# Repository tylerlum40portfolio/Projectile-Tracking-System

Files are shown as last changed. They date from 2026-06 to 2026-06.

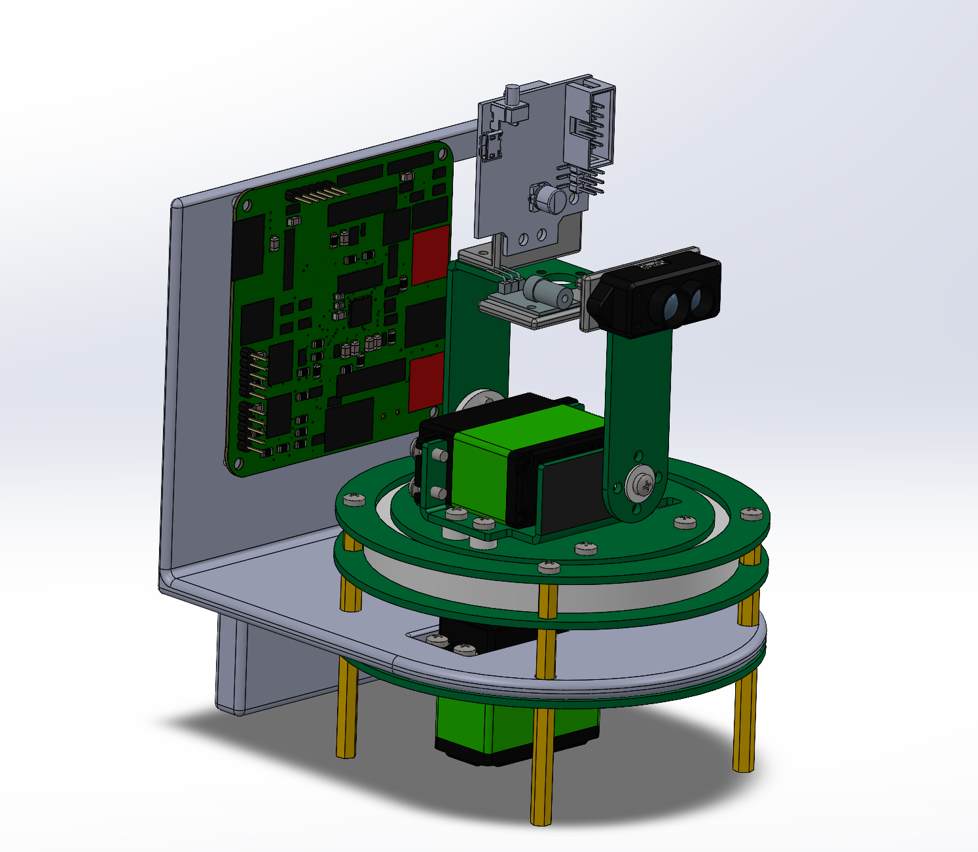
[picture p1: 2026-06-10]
images/Full 3D Assembly.png

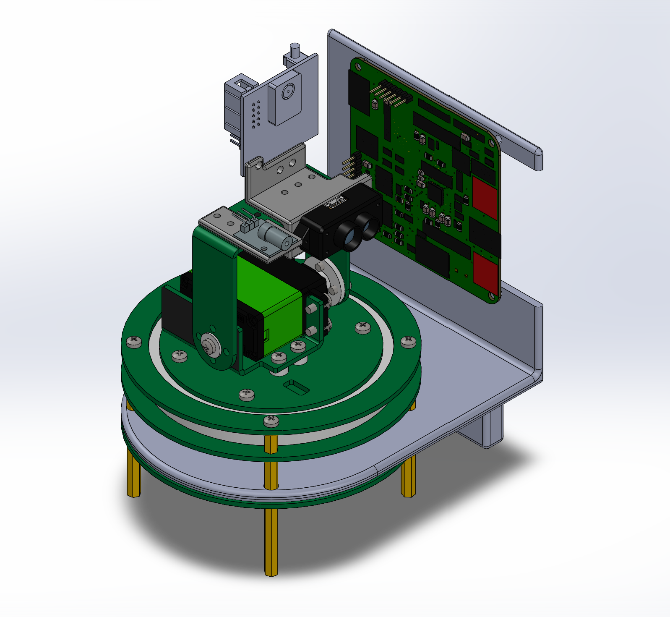
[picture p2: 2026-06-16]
images/fig-16-full-assembly.png

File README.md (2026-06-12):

# Pan-Tilt Laser Tracker

## Overview

The Pan-Tilt Laser Tracker is an STM32F411-based embedded mechatronic system designed to automatically detect, track, and indicate the location of a target in real time. The system combines computer vision, distance sensing, embedded control, and custom electronics into a single integrated platform.

A Pixy2 vision camera is used to detect a colored target and determine its position within the camera image. A TF-Luna LiDAR sensor provides distance measurements to validate target range. A custom controller processes this information and commands pan and tilt motors to continuously align the system with the target. A laser module is used to indicate the current tracked location.

The project was developed as part of ME 405 Mechatronics at California Polytechnic State University, San Luis Obispo and demonstrates many of the embedded systems, control, sensing, and software engineering concepts covered throughout the course.

---

## Team Members

- Tyler Lum
- Colby Cordoba
- Sam Nunes

Mechanical Engineering – Mechatronics

California Polytechnic State University, San Luis Obispo

---

## Project Features

### Sensing

- Real-time target detection using a Pixy2 vision sensor
- Distance measurement using TF-Luna LiDAR
- Target validation based on camera and distance data
- Sensor data filtering and validation

### Actuation

- Pan-axis motor control
- Tilt-axis motor control
- Laser target indication
- Closed-loop target tracking

### Embedded Systems

- STM32F411 microcontroller
- SPI communication with Pixy2 camera
- UART communication with TF-Luna LiDAR
- PWM motor control using STM32 timers
- GPIO control for laser operation
- Modular embedded C firmware architecture

---

## Major Hardware

### Electrical Components

- STM32F411 Microcontroller
- Pixy2 Camera
- TF-Luna LiDAR Sensor
- Custom PCB
- Laser Module
- Voltage Regulation Circuitry
- SWD Programming Interface

### Mechanical Components

- Pan/Tilt Tracking Assembly
- Camera Mount
- LiDAR Mount
- Laser Mount
- PCB Mounting Bracket
- Structural Support Components

---

## Software Architecture

The firmware is organized into modular drivers and application layers.

### Main Application

The main application initializes all peripherals, configures the hardware interfaces, and executes the primary tracking loop. It coordinates communication between the sensors, controller, and actuators.

### Controller Module

The controller module serves as the intelligence layer of the system. It processes Pixy2 target information and LiDAR distance measurements, computes tracking error, and generates motor commands to maintain target alignment.

### Motor Driver

The motor driver provides an abstraction layer for pan and tilt actuation. The driver handles PWM generation, motor direction control, speed limiting, and safe motor shutdown.

### LiDAR Driver

The LiDAR driver manages UART communication with the TF-Luna sensor. The driver validates measurement frames, checks data integrity, and provides distance measurements to the controller.

### Pixy2 Driver

The Pixy2 driver handles SPI communication with the camera and processes detected object information. The driver extracts target location information used by the tracking controller.

### Laser Driver

The laser driver manages laser activation and indication logic based on controller state and target lock conditions.

---

## Tracking Algorithm

The tracking system operates using the following sequence:

1. Acquire target location from the Pixy2 camera.
2. Acquire distance measurement from the TF-Luna LiDAR.
3. Validate target detection and range.
4. Compute horizontal and vertical tracking error.
5. Generate pan and tilt motor commands.
6. Update motor outputs.
7. Activate laser when tracking criteria are satisfied.
8. Repeat continuously during operation.

---

## Mathematical Modeling and Sensor Processing

Several calculations are performed within the firmware to convert sensor measurements into motor commands.

### Pixel Error Calculation

The controller calculates the difference between the target position and the image center.

```text
Error = Target Position − Image Center
```

The resulting horizontal and vertical error values are used to determine pan and tilt corrections.

### Motor Command Generation

Tracking error is converted into motor commands using proportional control and output limiting to ensure stable operation.

### Distance Validation

LiDAR measurements are checked against valid operating ranges before tracking commands are issued. This prevents false target responses caused by invalid sensor readings.

---

## Repository Structure

```text
Projectile-Tracking-System/
│
├── Core/
│   ├── Inc/
│   └── Src/
│
├── Drivers/
│
├── docs/
│   └── Doxygen Documentation
│
├── images/
│   └── CAD Models, PCB Images, and Project Photos
│
├── index.html
├── README.md
├── Doxyfile
├── .gitignore
```

---

## Documentation

### Project Portfolio

https://tylerlum40portfolio.github.io/Projectile-Tracking-System/

### Doxygen Documentation

https://tylerlum40portfolio.github.io/Projectile-Tracking-System/docs/index.html

The Doxygen documentation contains:

- File documentation
- Function documentation
- Driver descriptions
- Data structures
- Source code references
- Module relationships

---

## Repository Requirements

This repository contains:

- Complete STM32 source code
- Doxygen-generated documentation
- Doxyfile configuration
- Project portfolio website
- CAD renders
- PCB images
- Wiring diagrams
- Mechanical design documentation
- Software architecture documentation
- Project media and demonstration materials

---

## Future Improvements

Potential future improvements include:

- Position feedback using encoders
- Improved target prediction algorithms
- Additional sensor fusion techniques
- Enhanced filtering for sensor measurements
- Improved tracking accuracy and stability

---

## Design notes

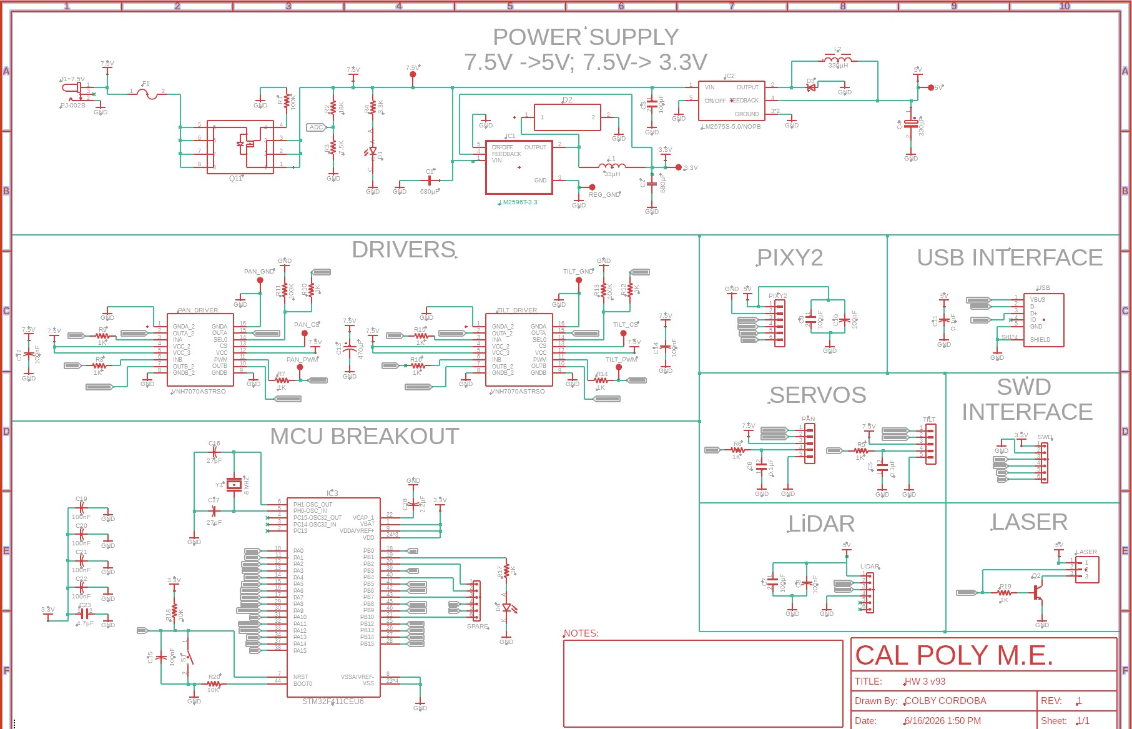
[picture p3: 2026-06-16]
images/fig-06-electrical-schematic.jpg

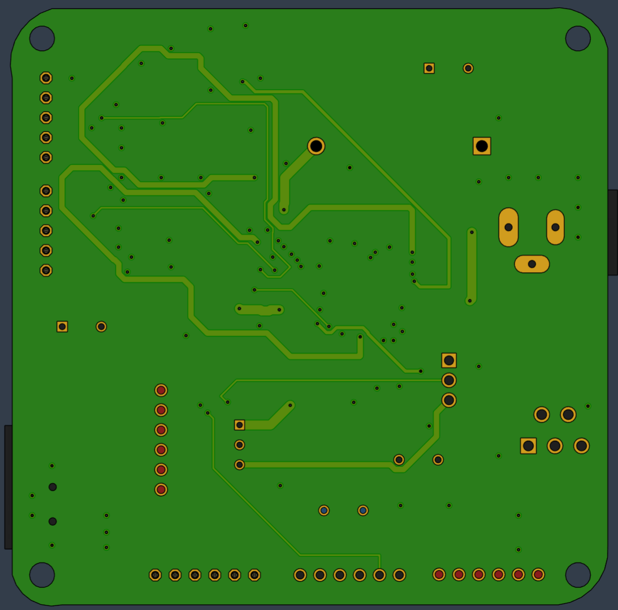
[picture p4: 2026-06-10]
images/PCB Bottom View 3D.png

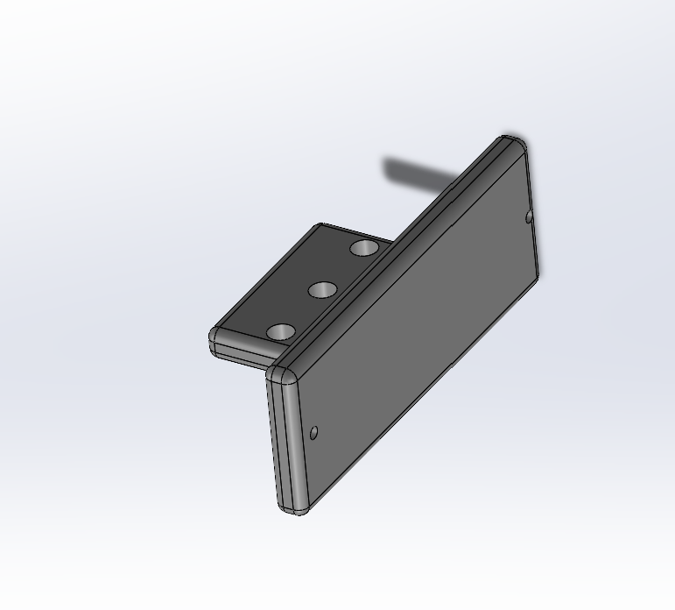
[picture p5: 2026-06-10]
images/Lidar Mount.png

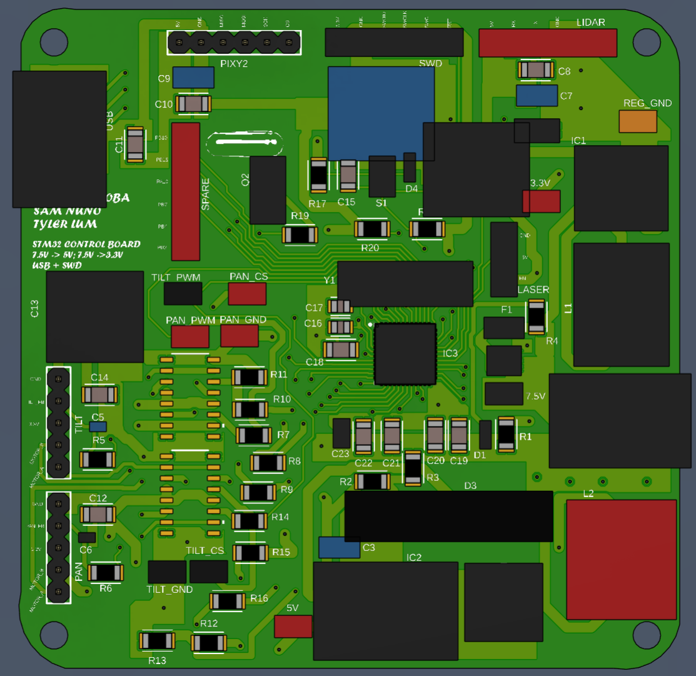
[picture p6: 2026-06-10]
images/PCB Top View 3D.png

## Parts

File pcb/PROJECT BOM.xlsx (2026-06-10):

Reference Designators | Quantity | Part Type | Value / Description | Package / Footprint | MPN / Product | Manufacturer | Supplier | Vendor Part Number | Link | Notes | JCL LINK | VERIFIED | PLACED | Column1
3.3V, 5V, 7.5V, PAN_CS, PAN_GND, TILT_GND, PAN_PWM, REG_GND, TILT_CS, TILT_PWM | 10 | Test Pad | Surface-mount PC test point, miniature | SMD | 5019 | Keystone Electronics | DigiKey | 36-5019-ND | https://www.digikey.com/en/products/detail/keystone-electronics/5019/3907343 | Rail/signal test pads from Fusion export | https://jlcpcb.com/partdetail/Keystone-5019/C238131 | TRUE | TRUE
C1,C2 | 2 | Aluminum Electrolytic Capacitor | 680 µF, 35 V, ±20%, low-impedance electrolytic capacitor, 2.25 A ripple current @ 100 kHz | Radial Can, Through Hole, 10 mm diameter, 5.00 mm lead spacing | 35ZLH680MEFC10X23 | Rubycon | DigiKey | 1189-1749-ND | https://www.digikey.sk/en/products/detail/rubycon/35ZLH680MEFC10X23/3563861 | Polarized: + to VIN or 3.3 V rail, - to GND. Place close to regulator pins. | https://jlcpcb.com/partdetail/Rubycon-35ZLH680MEFC10X23/C338198 | TRUE | TRUE
C3, C7, C9 | 3 | Ceramic capacitor | 100uF, 10V, X5R | CAPC3216X190N | GRM31CR61A107MEA8L | Murata Electronics | DigiKey | 490-GRM31CR61A107MEA8LCT-ND | https://www.digikey.sk/en/products/detail/murata-electronics/GRM31CR61A107MEA8L/16033775 | Quantity updated to match Fusion export; previous listed quantity was 2 | https://jlcpcb.com/partdetail/948963-GRM31CR61A107MEA8L/C883598 | TRUE | TRUE
C4 | 1 | Aluminum electrolytic capacitor | 330 µF, 25 V, ±20%, polarized, radial through-hole, 7000 hrs @ 105°C | Radial can, D8.0 mm, 3.5 mm lead spacing | 25YXJ330M8X11.5 | Rubycon | DigiKey | 25YXJ330M8X11.5-ND | https://www.digikey.at/en/products/detail/rubycon/25YXJ330M8X11-5/3563355 | 5V regulator output bulk capacitor | https://jlcpcb.com/partdetail/Rubycon-25YXJ330M8X115/C88788 | TRUE | TRUE
C5, C6 | 2 | Ceramic capacitor | 100nF / 0.1uF, 10V, X7R | CAPC1005X55N | CL05B104KP5NNNC | Samsung Electro-Mechanics | DigiKey | 1276-1002-1-ND | https://www.digikey.com/en/products/detail/samsung-electro-mechanics/CL05B104KP5NNNC/3886660 | 0402 footprint from Fusion matches this MPN | https://jlcpcb.com/partdetail/144388-CL05B104KP5NNNC/C133086 | TRUE | TRUE
C8, C10, C12, C14, C15, C19, C20, C21, C22 | 9 | Ceramic capacitor | 100nF / 0.1uF, 10V, X7R | CAPC3216X135 | CL05B104KP5NNNC | Samsung Electro-Mechanics | DigiKey | 1276-1002-1-ND | https://www.digikey.com/en/products/detail/samsung-electro-mechanics/CL05B104KP5NNNC/3886660 | Fusion footprint is 1206 | https://jlcpcb.com/partdetail/2297-CL31B104KCFNNNE/C1945 | TRUE | TRUE
C11 | 1 | Ceramic capacitor | 100nF / 0.1uF | CAPC3216X135 | CL05B104KP5NNNC | Samsung Electro-Mechanics | DigiKey | 1276-1002-1-ND | https://www.digikey.com/en/products/detail/samsung-electro-mechanics/CL05B104KP5NNNC/3886660 | Fusion footprint is 1206 | https://jlcpcb.com/partdetail/KEMET-C1206C104G8JAC7800/C1846371 | TRUE | TRUE
C13 | 1 | Aluminum electrolytic capacitor | 470uF, 50V, radial, +/-20% | CAPPRD500W60D1000H2000 | ECA-1HM471 | Panasonic Industry | DigiKey | P5185-ND | https://www.digikey.com/en/products/detail/panasonic-industry/ECA-1HM471/245044 | 7.5V motor-driver bulk capacitor; larger voltage rating than necessary but OK | https://jlcpcb.com/partdetail/PANASONIC-ECA1HM471/C713175 | TRUE | TRUE
C16, C17 | 2 | Ceramic capacitor | 27pF, 50V, C0G/NP0, ±5% | 0805 / 2012 metric | C0805C270J5GACAUT0 | KEMET | DigiKey | 399-18471-1-ND | https://www.digikey.com/en/products/detail/kemet/C0805C270J5GACAUT0/9468214 | Crystal load capacitors | https://jlcpcb.com/partdetail/2160-0805CG270J500NT/C1808 | TRUE | TRUE
C18 | 1 | Ceramic capacitor | 2.2µF, 50V, X7R, ±20% | 1206 / 3216 metric | C1206C225M5RACTU | KEMET | DigiKey | 399-13201-1-ND | https://www.digikey.com/en/products/detail/kemet/C1206C225M5RACTU/2215541 | VCAP_1 capacitor | https://jlcpcb.com/partdetail/KEMET-C1206C225K5RACTU/C2167253 | TRUE | TRUE
C23 | 1 | Ceramic capacitor | 4.7uF, 25V, X5R, 0805, +/-10% | CAPC2012X140N | CL21A475KAQNNNE | Samsung Electro-Mechanics | DigiKey | 1276-1244-1-ND | https://www.digikey.com/en/products/detail/samsung-electro-mechanics/CL21A475KAQNNNE/3886902 | MCU 3.3V local bulk capacitor | https://jlcpcb.com/partdetail/2131-CL21A475KAQNNNE/C1779 | TRUE | TRUE
D1 | 1 | LED | Blue LED, 470nm, 0603, Vf typ 3.3V, 20mA | LEDM1608X80 | LTST-C190TBKT | Lite-On Inc. | DigiKey | 160-1646-1-ND | https://www.digikey.com/en/products/detail/liteon/LTST-C190TBKT/388529 | Indicator LED; better for 5V or 7.5V rail than 3.3V rail | https://jlcpcb.com/partdetail/LiteOn-LTSTC190TBKT/C125096 | TRUE | TRUE
D2 | 1 | Schottky Diode | 20 V, 5 A Schottky rectifier diode, Vf 390 mV @ 3 A | SOD-128 / PMDTM Surface Mount | RSX501LAM20TR | Rohm Semiconductor | DigiKey | RSX501LAM20CT-ND | https://www.digikey.com/en/products/detail/rohm-semiconductor/RSX501LAM20TR/7318348 | Use only if LM2596 input is ≤16 V. | https://jlcpcb.com/partdetail/ROHMSemicon-RSX501LAM20TR/C253526 | TRUE | TRUE
D3 | 1 | Schottky Diode | 40V, 3A, DO-201AD axial | DIOAD2120W130L950D530P | 1N5822 | STMicroelectronics | DigiKey | 497-11370-1-ND | https://www.digikey.com/en/products/detail/stmicroelectronics/1N5822/1037332 | LM2575 freewheel/catch diodes; listing marked obsolete | https://jlcpcb.com/partdetail/STMicroelectronics-1N5822/C915962 | TRUE | TRUE
D4 | 1 | LED | Amber LED, 592nm, 0603, Vf typ 1.9V | LED_HSMA-C190 | HSMA-C190 | Broadcom Limited | DigiKey | 516-1423-1-ND | https://www.digikey.com/en/products/detail/broadcom-limited/HSMA-C190/637684 | Indicator / heartbeat LED; good for 3.3V with proper series resistor | https://jlcpcb.com/partdetail/BroadcomLimited-HSMAC190/C6571615 | TRUE | TRUE
DCPOWERJACKD~7.5V | 1 | DC barrel power jack | 2.5 mm ID / 5.5 mm OD, right-angle through-hole jack, 24 VDC, 5 A, 3 contacts, normally closed switch | Through-hole, right-angle barrel jack | PJ-002BH | Same Sky / formerly CUI Devices | DigiKey | CP-002BH-ND | https://www.digikey.com/en/products/detail/same-sky-formerly-cui-devices/PJ-002B/96965 | Main 7.5V power input connector | https://jlcpcb.com/partdetail/CUI-PJ002BH/C22359705 | TRUE | TRUE
F1 | 1 | Fuse | 10 A 50 V Fuse Board Mount | FUSC3215X83N | 0685P9100-01 | BEL Fuse | DigiKey | 2223-PJ-105BH-MSMT-TR-ND | https://www.digikey.com/en/products/detail/bel-fuse-inc/0685P9100-01/10057383 | BELFUSE 0685P9100-01 footprint/value | https://jlcpcb.com/partdetail/Shenzhen_JDTFuse-JFC12062100FS/C136354 | TRUE | TRUE
IC1 | 1 | DC-DC Buck Switching Regulator IC | Fixed 3.3 V output, 3 A, step-down regulator, 4.5 V–40 V input, 150 kHz | TO-220-5 Formed Leads / Through Hole | LM2596T-3.3/NOPB | Texas Instruments | DigiKey | LM2596T-3.3/NOPB-ND | https://www.digikey.com/en/products/detail/texas-instruments/LM2596T-3-3-NOPB/363707 | 7.5V to 3.3V regulator; through-hole package | https://jlcpcb.com/partdetail/TexasInstruments-LM2596T_3_3NOPB/C1355424 | TRUE | TRUE
IC2 | 1 | Buck regulator IC | Fixed 5V output, 1A, 52kHz, TO-263/DDPAK-5 | VREG_LM2575S-5.0/NOPB | LM2575S-5.0/NOPB | Texas Instruments | DigiKey | LM2575S-5.0/NOPB-ND | https://www.digikey.com/en/products/detail/texas-instruments/LM2575S-5-0-NOPB/363646 | 7.5V to 5V regulator | https://jlcpcb.com/partdetail/TexasInstruments-LM2575S_5_0NOPB/C2865532 | TRUE | TRUE
IC3 | 1 | Microcontroller | STM32F411, ARM Cortex-M4, 512KB Flash, 128KB RAM, 48-UFQFPN | STM32F411CEU6 | STM32F411CEU6 | STMicroelectronics | DigiKey | 497-14907-ND | https://www.digikey.com/en/products/detail/stmicroelectronics/STM32F411CEU6/4935720 | Main MCU; verify exact 48-UFQFPN exposed-pad footprint | https://jlcpcb.com/partdetail/STMicroelectronics-STM32F411CEU6/C60420 | TRUE | TRUE
L1 | 1 | Power Inductor | 33 µH, 5 A shielded drum core wirewound inductor, 75.4 mΩ max DCR, 7.6 A saturation current | 2-SMD, J-Lead / 10.7 mm × 10.0 mm | ETQ-P5M330YFC | Panasonic Industry | DigiKey | PCD2434CT-ND | https://www.digikey.com/en/products/detail/panasonic-industry/ETQ-P5M330YFC/5357810 | Provide enough copper area because it may warm up at high current. | https://jlcpcb.com/partdetail/PANASONIC-ETQP5M330YFC/C542339 | TRUE | TRUE
L2 | 1 | Power inductor | 330uH, shielded, 1.5A, DCR 430mOhm max | WE-PD_1210 | 7447709331 | Wurth Elektronik | DigiKey | 732-1698-1-ND | https://www.digikey.com/en/products/detail/w%C3%BCrth-elektronik/7447709331/1994059 | Inductors for 3.3V and 5V buck regulators | https://jlcpcb.com/partdetail/WurthElektronik-7447709331/C2041321 | TRUE | TRUE
LAZER | 1 | Male header | 3-position, 2.54mm pitch, vertical, through-hole, unshrouded | WURTH_61300311121 | 61300311121 | Wurth Elektronik | DigiKey | 732-5316-ND | https://www.digikey.com/en/products/detail/w%C3%BCrth-elektronik/61300311121/4846825 | 3-pin laser module connector | https://jlcpcb.com/partdetail/WurthElektronik-61300311121/C2915006 | TRUE | TRUE
LIDAR, SPARE, SWD | 3 | Male header | 6-position, 2.54mm pitch, vertical, through-hole, unshrouded | 1x06 / 2.54mm THT | 61300611121 | Wurth Elektronik | DigiKey | 732-5319-ND | https://www.digikey.com/en/products/detail/w%C3%BCrth-elektronik/61300611121/4846833 | 6-pin headers from Fusion export; verify exact DigiKey link/part | https://jlcpcb.com/partdetail/WurthElektronik-61300611121/C5444523 | TRUE | TRUE
PAN, TILT | 2 | Pin header | 5-position, 2.54mm pitch, vertical, through-hole, unshrouded | 1x05 / 2.54mm THT | 61300511121 | Würth Elektronik | DigiKey | 732-5318-ND | https://www.digikey.com/en/products/detail/w%C3%BCrth-elektronik/61300511121/4846831 | Servo modified 5-wire connectors; exact MPN not provided | https://jlcpcb.com/partdetail/WurthElektronik-61300511121/C6461551 | TRUE | TRUE
PAN_DRIVER, TILT_DRIVER | 2 | Brushed DC motor driver IC | 4–28 V supply/load, 15 A output, PWM interface, dual half-bridge, AEC-Q100 automotive | 16-SOIC, 0.154" / 3.90 mm width, surface mount | VNH7070ASTR | STMicroelectronics | DigiKey | 497-17630-1-ND / 497-17630-2-ND / 497-17630-6-ND | https://www.digikey.com/en/products/detail/stmicroelectronics/VNH7070ASTR/7313214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 | Pan and tilt motor drivers; DigiKey listing marked obsolete | https://jlcpcb.com/partdetail/STMicroelectronics-VNH7070ASTR/C2150622 | TRUE | TRUE
PIXY2 | 1 | Male header | 6-position, 2.54mm pitch, vertical, through-hole, unshrouded | 1x06 / 2.54mm THT | 61300611121 | Wurth Elektronik | DigiKey | 732-5319-ND | https://www.digikey.com/en/products/detail/w%C3%BCrth-elektronik/61300611121/4846833 | Pixy2 board connector; exact MPN not provided | https://jlcpcb.com/partdetail/WurthElektronik-61300611121/C5444523 | TRUE | TRUE
Q1 | 1 | P-channel MOSFET | 30V, 18A, PowerPAK 1212-8, low Rds(on) | POWERPAK_1212-8 | SIS413DN-T1-GE3 | Vishay Siliconix | DigiKey | SIS413DN-T1-GE3CT-ND | https://www.digikey.com/en/products/detail/vishay-siliconix/SIS413DN-T1-GE3/4142142 | Input reverse-polarity / high-side protection MOSFET | https://jlcpcb.com/partdetail/VishayIntertech-SIS413DN_T1GE3/C145006 | TRUE | TRUE
R1, R11, R13 | 3 | Resistor | 100kΩ, ±1%, 1/4W, thick film | 1206 / 3216 metric | RC1206FR-07100KL | YAGEO | DigiKey | 311-100KFRCT-ND | https://www.digikey.com/en/products/detail/yageo/RC1206FR-07100KL/728492 | Generic 1206 resistor; exact MPN not provided | https://jlcpcb.com/partdetail/YAGEO-RC1206FR07100KL/C137393 | TRUE | TRUE
R2 | 1 | Resistor | 18kΩ, ±1%, 1/4W, thick film | 1206 / 3216 metric | RC1206FR-0718KL | YAGEO | DigiKey | 311-18.0KFRCT-ND | https://www.digikey.com/en/products/detail/yageo/RC1206FR-0718KL/728592 | Generic 1206 resistor; exact MPN not provided | https://jlcpcb.com/partdetail/YAGEO-RC1206FR0718KL/C137379 | TRUE | TRUE
R3 | 1 | Resistor | 7.5kΩ, ±1%, 1/4W, thick film | 1206 / 3216 metric | RC1206FR-077K5L | YAGEO | DigiKey | 311-7.50KFRCT-ND | https://www.digikey.com/en/products/detail/yageo/RC1206FR-077K5L/729079 | Generic 1206 resistor; exact MPN not provided | https://jlcpcb.com/partdetail/YAGEO-RC1206FR077K5L/C137232 | TRUE | TRUE
R4 | 1 | Resistor | 3.3kΩ, ±1%, 1/4W, thick film | 1206 / 3216 metric | RC1206FR-073K3L | YAGEO | DigiKey | 311-3.30KFRCT-ND | https://www.digikey.com/en/products/detail/yageo/RC1206FR-073K3L/728766 | Generic 1206 resistor; exact MPN not provided | https://jlcpcb.com/partdetail/YAGEO-RC1206FR073K3L/C137292 | TRUE | TRUE
R5, R6, R7, R8, R9, R10, R12, R14, R15, R16, R17, R19 | 12 | Resistor | 1kΩ, ±1%, 1/4W, thick film | 1206 / 3216 metric | RC1206FR-071KL | YAGEO | DigiKey | 311-1.00KFRCT-ND | https://www.digikey.com/en/products/detail/yageo/RC1206FR-071KL/728387 | Generic 1206 resistor; exact MPN not provided | https://jlcpcb.com/partdetail/YAGEO-RC1206FR071KL/C131398 | TRUE | TRUE
R18, R20 | 2 | Resistor | 10kΩ, ±1%, 1/4W, thick film | 1206 / 3216 metric | RC1206FR-0710KL | YAGEO | DigiKey | 311-10.0KFRCT-ND | https://www.digikey.com/en/products/detail/yageo/RC1206FR-0710KL/728483 | Generic 1206 resistor; exact MPN not provided | https://jlcpcb.com/partdetail/YAGEO-RC1206FR0710KL/C132649 | TRUE | TRUE
S1 | 1 | Tactile switch | Reset pushbutton | SW_B3U-1000PM | B3U-1000PM | Omron | DigiKey | SW1020CT-ND | https://www.digikey.com/en/products/detail/omron-electronics-inc-emc-div/B3U-1000PM/11312954 | Exact supplier link not provided | https://jlcpcb.com/partdetail/OmronElectronics-B3U1000PM/C2934715 | TRUE | TRUE
USB | 1 | USB connector | Mini USB-B receptacle, 5 position, SMD, right angle | AMPHENOL_10033526-N3212LF | 10033526-N3212LF | Amphenol ICC (FCI) | DigiKey | 609-4700-1-ND | https://www.digikey.com/en/products/detail/amphenol-cs-fci/10033526-N3212LF/4292074 | USB interface connector | https://jlcpcb.com/partdetail/AmphenolICC-10033526N3212LF/C428494 | TRUE | TRUE
Y1 | 1 | Crystal | 8MHz, 18pF load capacitance, +/-50ppm, SMD HC-49/US | XTAL_ABLS-LR-8.000MHZ-T | ABLS-LR-8.000MHZ-T | Abracon LLC | DigiKey | 535-10173-1-ND | https://www.digikey.com/en/products/detail/abracon-llc/ABLS-LR-8-000MHZ-T/2184116 | STM32 external high-speed oscillator / HSE | https://jlcpcb.com/partdetail/ECS-ECS_80_18_5PXTR/C312598 | TRUE | TRUE
Q2 | 1 | NPN BJT Transistor | 40 V, 200 mA, 300 MHz, 625 mW general-purpose NPN transistor | TO-92 / TO-226-3 Through Hole | 2N3904 | Diotec Semiconductor | DigiKey | 5245-2N3904CT-ND | https://www.digikey.com/en/products/detail/dcomponents/2N3904/13575042 | Emitter to GND, Base through 1 kΩ from LASER_EN, Collector to laser negative. | https://jlcpcb.com/partdetail/DIOTEC-2N3904/C3201586 | TRUE | TRUE
LIDAR module | 1 | Off-board module | TF-Luna single-point LiDAR, 0.2m-8m, UART/I2C, 5V, 6-pin cable | TF-Luna LiDAR Range Finder Sensor | Wishiot / Benewake-style module | Amazon |  | https://www.amazon.com/dp/B09PZ559ZB?ref=ppx_yo2ov_dt_b_fed_asin_title
LASER module | 1 | Off-board module | KY-008 laser transmitter module, 5V, 650nm, 3-pin | KY-008 | KOOKBOOK | Amazon |  | https://www.amazon.com/dp/B07S9B5W98?ref=ppx_yo2ov_dt_b_fed_asin_title
MECH_PTZ | 1 | Mechanical assembly | Yahboom 2DOF electric pan/tilt platform, selected without servo/control board | 2DOF PTZ / SKU 6000301351 | Yahboom | Yahboom |  | https://category.yahboom.net/products/2dof-ptz
PIXY2 module | 1 | Off-board module | Pixy2 / Pixy 2.1 smart vision sensor, object tracking camera | Pixy2 / Pixy 2.1 | Charmed Labs | Amazon |  | https://www.amazon.com/Charmed-Labs-Pixy2-Vision-Sensor/dp/B07D1CLYD2
PS1 / External Supply | 1 | AC/DC wall adapter | 7.5V DC wall adapter, 7.5W, barrel plug | Off-board power adapter | Guy-Tech 7.5V adapter compatible with Triad WSU075-1000-R | Guy-Tech |  | https://www.amazon.com/Guy-Tech-Adapter-Compatible-Magnetics-WSU075-1000-R/dp/B0FH6N6MBS

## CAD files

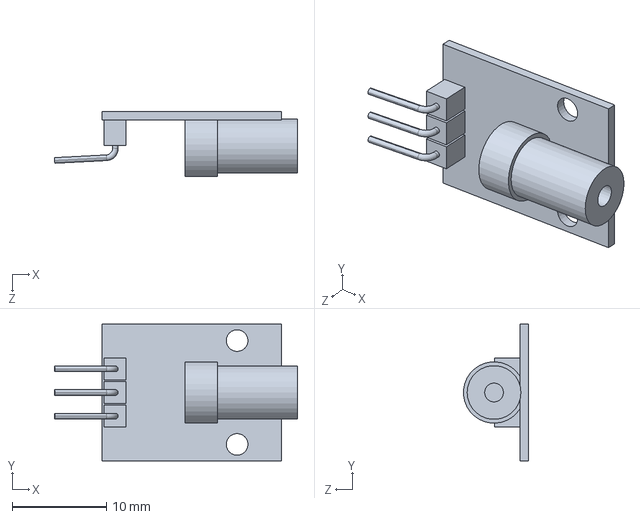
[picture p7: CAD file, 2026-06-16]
CAD/XC4490.SLDPRT
25.8 x 14.5 x 6.89 mm

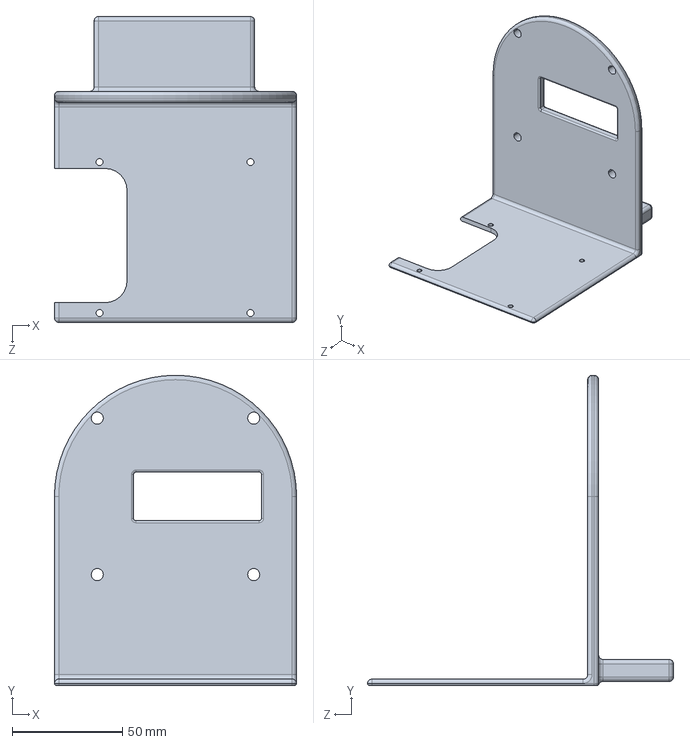
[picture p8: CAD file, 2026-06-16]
CAD/PCB_MOUNT.SLDPRT
110.0 x 141.0 x 139.0 mm

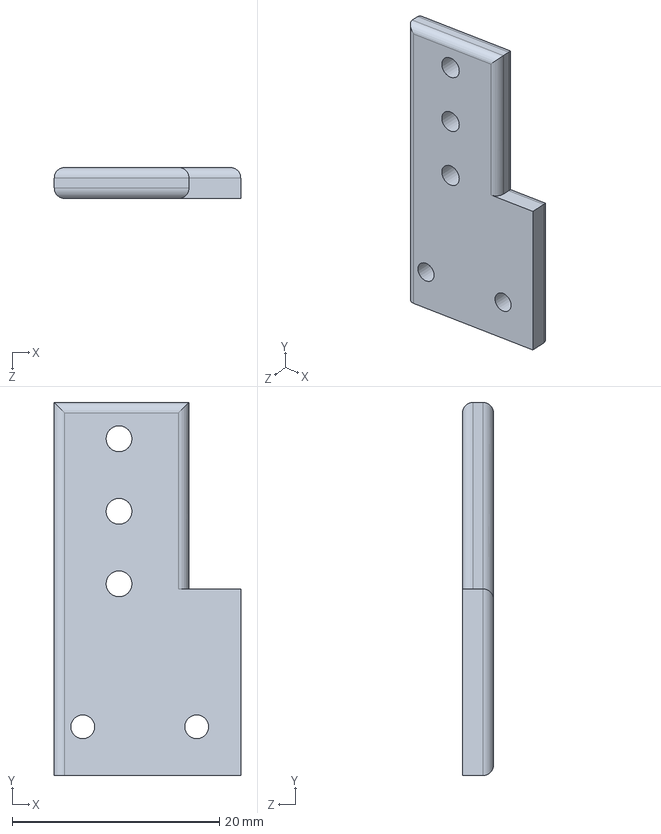
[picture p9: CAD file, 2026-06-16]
CAD/LASER_MOUNT.SLDPRT
18.0 x 36.0 x 3.00 mm

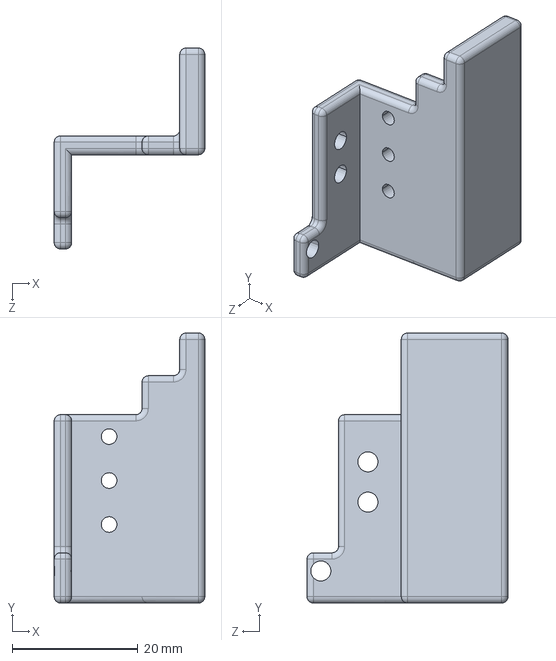
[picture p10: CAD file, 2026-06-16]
CAD/CAM&LIDAR_MOUNT.SLDPRT
24.0 x 43.0 x 32.0 mm

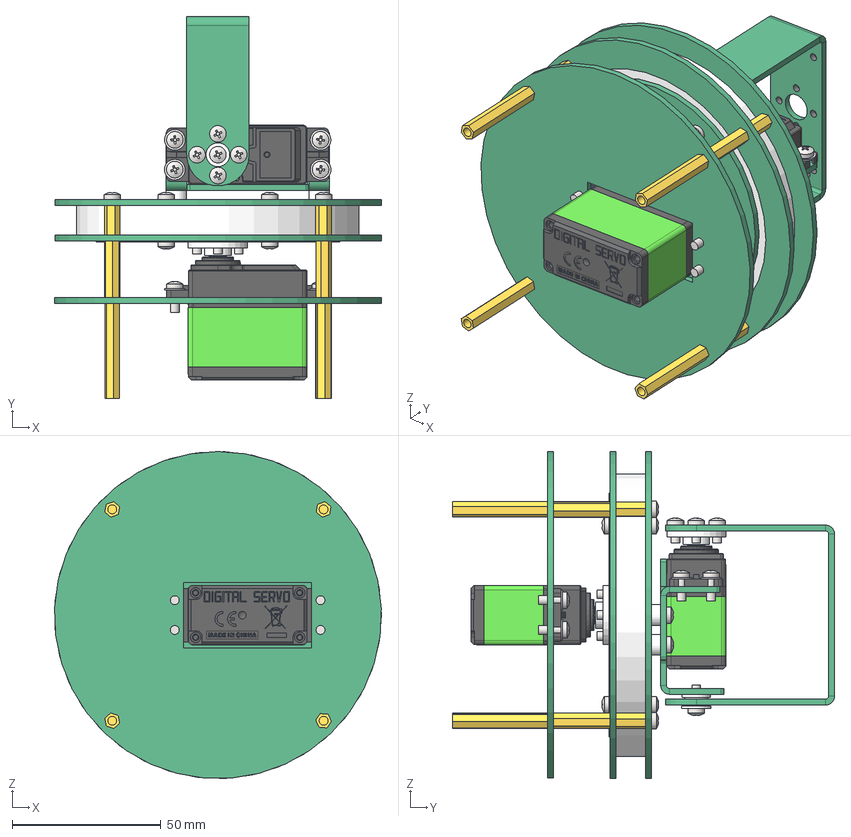
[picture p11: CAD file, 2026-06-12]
CAD/2DOF PTZ.step
110.0 x 128.5 x 110.0 mm
DJWSZ-01_1^jc-24kg_asm(2)_20KG¶æ»ú x 2
DJWSS-01_1^jc-24kg_asm(2)_20KG¶æ»ú x 2
DJWSX-01_1^jc-24kg_asm(2)_20KG¶æ»ú x 2
CL_101_1^jc-24kg_asm(2)_20KG¶æ»ú x 2
61025ZC-01_1^jc-24kg_asm(2)_20KG¶æ»ú x 4
CL_105_1^jc-24kg_asm(2)_20KG¶æ»ú x 2
ZDJ_1_1_1_1^jc-24kg_asm(2)_20KG¶æ»ú x 2
402ZGY-01_1^jc-24kg_asm(2)_20KG¶æ»ú x 2
GZA-01_1^jc-24kg_asm(2)_20KG¶æ»ú x 2
GZB-01_1^jc-24kg_asm(2)_20KG¶æ»ú x 2
DINGWEIQI_2_1_1_1^jc-24kg_asm(2)_20KG¶æ»ú x 2
382SGY-01_1^jc-24kg_asm(2)_20KG¶æ»ú x 2
382SGY-02_1^jc-24kg_asm(2)_20KG¶æ»ú x 2
¶æ»úÍ· x 2
ÔÆÌ¨îÓ½ð¡ªµ ×²¿
ÍÖùM3-32+6mm µ¥Í¨ 1. 1 x 4
¶þ×ÔÓÉ¶ÈÔÆÌ¨îÓ ½ð¡ª¶æ»úÅÌ°²×° °å
¶þ×ÔÓÉ¶ÈÔÆÌ¨îÓ ½ð¡ª¶æ»ú¹Ì¶¨°å
¶þ×ÔÓÉ¶ÈÔÆÌ¨îÓ ½ð¡ª¶æ»úÐý×ª¼Ü
·¨À¼Öá³Ð
plain washers-n series-grade a gb_GB_FASTENER_WASHER_PWNA 3 x 8
cross recessed pan head screws gb_GB_CROSS_SCREWS_TYPE1 M3X8-8 H typ e-N x 9
cross recessed pan head screws gb_GB_CROSS_SCREWS_TYPE1 M3X6-6 H typ e-N x 22
20KG½ðÊô¶æÅÌ£¨ ´ý¶¨£© x 2
·¨À¼Öá³ÐF693ZZ
3-7-3¸ôÀëÖù x 4
¶þ×ÔÓÉ¶ÈÔÆÌ ¨îÓ½ð¡ªÍâÔÆÌ¨ x 2
Éî¹µÇòÖá³Ð6815 ZZ
ÍÖùM3-19 Ë«Í¨ 1.1 x 4
ÔÆÌ¨îÓ½ð¡ª¶ æ»ú¹Ì¶¨°²×°°å
ÍÖùM3-10+6mm µ¥Í¨ 1. 1 x 4
ÍÖùM3-9 Ë«Í¨ 1.1 x 4
cross recessed pan head screws gb_GB_CROSS_SCREWS_TYPE1 M3X8-8 H typ e-C x 4

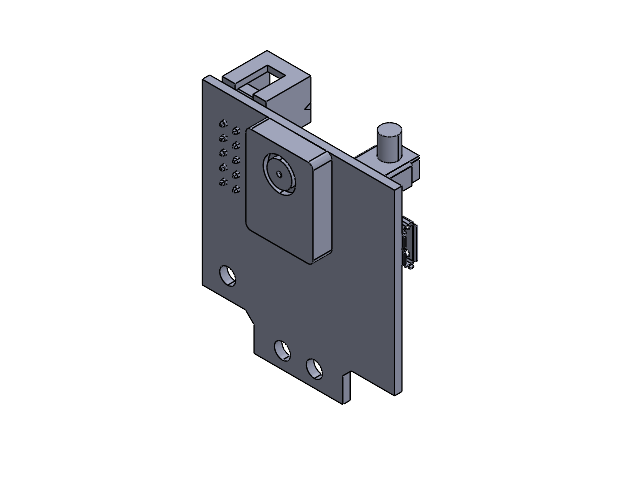
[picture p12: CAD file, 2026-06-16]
CAD/Pixy 2.SLDASM
pixy.STEP
capacitor.STEP
micro usb.STEP
DS1013-10SSiB.STEP
DS1022-1x3RD61.STEP x 2
button.STEP

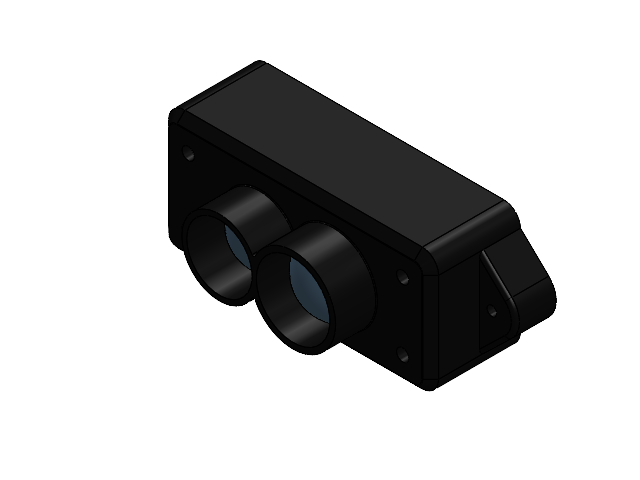
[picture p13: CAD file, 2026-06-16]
CAD/TF Mini Lidar.SLDASM
GH-4pin-connector.step
eBom-FreeParts.step

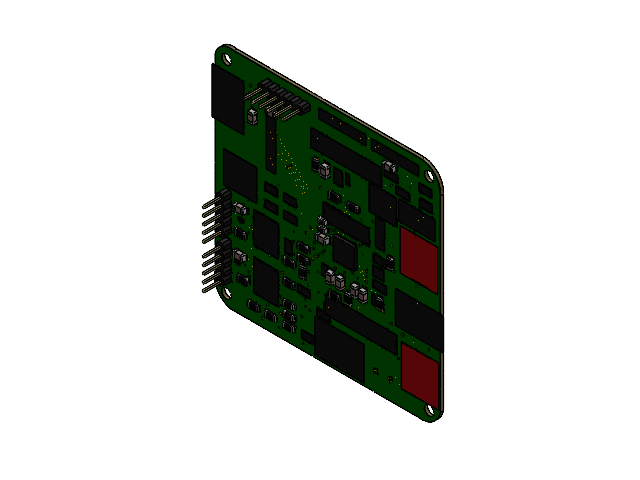
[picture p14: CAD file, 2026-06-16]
CAD/HW 3.SLDASM
9216955.f3d .step x 11
1X05 v2.step x 2
1X06 v2.step
Model.step
9216945.f3d .step x 2
2026-04-19-18-31-12-025.step
2026-04-19-18-31-12-034.step
POWERPAK_1212-8.step
RESC3216X70.step x 19
AMPHENOL_10033526-N3212LF.step
DIOAD2120W130L950D530P.step x 2
WURTH_61300311121.step
61300611121.step x 3
SW_B3U-1000PM.step
CAPC1005X55N.step x 2
CAPPRD350W60D800H1150.step
CAPPRD500W60D1025H1750.step
CAPC3216X190N.step x 4
LM257533WT.step
VREG_LM2575S-5.0_NOPB.step
SOIC127P600X175-16N.step x 2
WE-PD_1210.step x 2
KEYSTONE_5019.step x 10
CAPC2012X140N.step
CAPPRD500W60D1000H2000.step
LED_HSMA-C190.step
LEDM1608X80.step
CUI_PJ-002B.step
2026-04-19-18-31-11-345.step
2026-04-19-18-31-11-652.step
2026-04-19-18-31-11-678.step
2026-04-19-18-31-11-702.step
2026-04-19-18-31-11-729.step

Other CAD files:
CAD/2DOF PTZ.SLDASM
pcb/Final PCB Design.f3z

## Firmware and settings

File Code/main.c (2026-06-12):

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
/* Includes ------------------------------------------------------------------*/
#include "main.h"

/* USER CODE BEGIN Includes */
#include "Laser.h"
#include "LiDAR.h"
#include "motor_driver.h"
#include "pixy2_camera.h"
#include "controller.h"
#include <stdbool.h>
/* USER CODE END Includes */

/* USER CODE BEGIN PD */
#define X_OFFSET_CORRECTION   8
#define Y_OFFSET_CORRECTION   8
/* USER CODE END PD */

ADC_HandleTypeDef hadc1;

SPI_HandleTypeDef hspi1;

TIM_HandleTypeDef htim3;
TIM_HandleTypeDef htim4;

UART_HandleTypeDef huart2;

/* USER CODE BEGIN PV */

/** @brief Global LiDAR object storing the latest distance measurement. */
Lidar_t      lidar;

/** @brief Latest target selected from the Pixy2 camera frame. */
PixyTarget_t camera_target;

/* Set to 1 by TIM3 ISR each tick; cleared by main loop after processing */
volatile uint8_t control_tick = 0u;

int16_t last_pan_speed = 0;
int16_t last_tilt_speed = 0;
uint8_t lost_count = 0;
float pan_cmd = 0;
float tilt_cmd = 0;
/* USER CODE END PV */

void SystemClock_Config(void);
static void MX_GPIO_Init(void);
static void MX_TIM4_Init(void);
static void MX_SPI1_Init(void);
static void MX_USART2_UART_Init(void);
static void MX_TIM3_Init(void);
static void MX_ADC1_Init(void);
/**
  * @brief  The application entry point.
  * @retval int
  */
int main(void)
{

  /* MCU Configuration--------------------------------------------------------*/

  /* Reset of all peripherals, Initializes the Flash interface and the Systick. */
  HAL_Init();

  /* Configure the system clock */
  SystemClock_Config();

  /* Initialize all configured peripherals */
  MX_GPIO_Init();
  MX_TIM4_Init();
  MX_SPI1_Init();
  MX_USART2_UART_Init();
  MX_TIM3_Init();
  MX_ADC1_Init();
  /* USER CODE BEGIN 2 */

  Laser_Init();

  Laser_On();
  HAL_Delay(300);
  Laser_Off();
  HAL_Delay(300);
  Laser_On();
  HAL_Delay(300);
  Laser_Off();

  Lidar_Init(&lidar, &huart2);
  MotorDriver_Init();
  Pixy2_Init();
  Controller_Init();

  Controller_HomeTiltBlocking(3000u);

  /* Start TIM3 — fires HAL_TIM_PeriodElapsedCallback at 20 Hz */
  HAL_TIM_Base_Start_IT(&htim3);

  /* USER CODE END 2 */

  /* Infinite loop */
  /* USER CODE BEGIN WHILE */
  while (1)
  {
    /* USER CODE END WHILE */

    /* USER CODE BEGIN 3 */
	  while (1)
	  {
	      /* USER CODE END WHILE */

	      /* USER CODE BEGIN 3 */

	      bool target_found = Camera_FindTarget(&camera_target);

	      camera_target.x_error -= X_OFFSET_CORRECTION;
	      camera_target.y_error -= Y_OFFSET_CORRECTION;

	      if (target_found && camera_target.target_detected)
	      {
	          int16_t pan_speed = 0;
	          int16_t tilt_speed = 0;

	          /*
	           * Target is detected.
	           * Tracking fully controls pan and tilt.
	           * Do NOT call Controller_HomeTiltStep() in this block.
	           */
	          lost_count = 0;

	          /* PAN CONTROL */
	          if (camera_target.x_error > PIXY2_X_DEADBAND ||
	              camera_target.x_error < -PIXY2_X_DEADBAND)
	          {
	              pan_speed = -camera_target.x_error * 10;

	              if (pan_speed > 0)
	              {
	                  pan_speed += 450;
	              }
	              else if (pan_speed < 0)
	              {
	                  pan_speed -= 450;
	              }
	          }

	          /* TILT CONTROL */
	          if (camera_target.y_error > PIXY2_Y_DEADBAND ||
	              camera_target.y_error < -PIXY2_Y_DEADBAND)
	          {
	              tilt_speed = camera_target.y_error * 10;

	              if (tilt_speed > 0)
	              {
	                  tilt_speed += 500;
	              }
	              else if (tilt_speed < 0)
	              {
	                  tilt_speed -= 500;
	              }
	          }

	          /* Clamp pan speed */
	          if (pan_speed > 1800)
	          {
	              pan_speed = 1800;
	          }
	          else if (pan_speed < -1800)
	          {
	              pan_speed = -1800;
	          }

	          /* Clamp tilt speed */
	          if (tilt_speed > 1500)
	          {
	              tilt_speed = 1500;
	          }
	          else if (tilt_speed < -1500)
	          {
	              tilt_speed = -1500;
	          }

	          /* ADC safety limits while tracking */
	          pan_speed = Controller_ApplyPanLimits(pan_speed);
	          tilt_speed = Controller_ApplyTiltLimits(tilt_speed);

	          last_pan_speed = pan_speed;
	          last_tilt_speed = tilt_speed;

	          if (pan_speed == 0)
	          {
	              pan_cmd = 0;
	          }

	          if (tilt_speed == 0)
	          {
	              tilt_cmd = 0;
	          }

	          /* Smooth motor commands */
	          pan_cmd  = 0.5f * pan_cmd  + 0.5f * pan_speed;
	          tilt_cmd = 0.5f * tilt_cmd + 0.5f * tilt_speed;

	          /* Apply ADC limits again after smoothing */
	          pan_cmd = Controller_ApplyPanLimits((int16_t)pan_cmd);
	          tilt_cmd = Controller_ApplyTiltLimits((int16_t)tilt_cmd);

	          PanMotor_Set((int16_t)pan_cmd);
	          TiltMotor_Set((int16_t)tilt_cmd);

	          Laser_On();
	      }
	      else
	      {
	          Laser_Off();

	          if (lost_count < 255)
	          {
	              lost_count++;
	          }

	          /*
	           * Very short target loss:
	           * Stop motors, but do NOT home yet.
	           * This prevents homing from fighting tracking when Pixy flickers.
	           */
	          if (lost_count < 8)
	          {
	              PanMotor_Set(0);
	              TiltMotor_Set(0);
	          }

	          /*
	           * Medium target loss:
	           * Now start bringing tilt back to vertical.
	           * Pan still stays stopped.
	           */
	          else if (lost_count < 25)
	          {
	              PanMotor_Set(0);
	              Controller_HomeTiltStep();

	              pan_cmd = 0;
	              tilt_cmd = 0;
	              last_pan_speed = 0;
	              last_tilt_speed = 0;
	          }

	          /*
	           * Long target loss:
	           * Full search mode.
	           * Controller_SearchMode() should keep pan stopped until tilt is vertical.
	           */
	          else
	          {
	              Controller_SearchMode();

	              pan_cmd = 0;
	              tilt_cmd = 0;
	              last_pan_speed = 0;
	              last_tilt_speed = 0;
	          }
	      }

	      HAL_Delay(20);

	      /* USER CODE END 3 */
	  }
  /* USER CODE END 3 */
  }
}

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
/* USER CODE BEGIN 4 */

/**
 * @brief Timer period elapsed callback used by the 20 Hz control loop.
 *
 * TIM3 triggers this callback at the configured control rate. The interrupt only
 * sets a flag, while the main loop performs the actual camera, LiDAR, motor, and
 * laser work. This avoids doing slow SPI/UART operations inside the interrupt.
 *
 * @param htim Pointer to the timer handle that generated the interrupt.
 */
void HAL_TIM_PeriodElapsedCallback(TIM_HandleTypeDef *htim)
{
    if (htim->Instance == TIM3)
    {
        control_tick = 1u;
    }
}

/* USER CODE END 4 */
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


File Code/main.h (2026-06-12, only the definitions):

#define PIXY_CS_Pin GPIO_PIN_4
#define PIXY_CS_GPIO_Port GPIOA
#define PIXY_SCK_Pin GPIO_PIN_5
#define PIXY_SCK_GPIO_Port GPIOA
#define PIXY_MISO_Pin GPIO_PIN_6
#define PIXY_MISO_GPIO_Port GPIOA
#define PIXY_MOSI_Pin GPIO_PIN_7
#define PIXY_MOSI_GPIO_Port GPIOA
#define PAN_INA_Pin GPIO_PIN_12
#define PAN_INA_GPIO_Port GPIOB
#define PAN_INB_Pin GPIO_PIN_13
#define PAN_INB_GPIO_Port GPIOB
#define TILT_INA_Pin GPIO_PIN_14
#define TILT_INA_GPIO_Port GPIOB
#define TILT_INB_Pin GPIO_PIN_15
#define TILT_INB_GPIO_Port GPIOB
#define LASER_SIGNAL_Pin GPIO_PIN_8
#define LASER_SIGNAL_GPIO_Port GPIOA
#define PAN_SEL0_Pin GPIO_PIN_5
#define PAN_SEL0_GPIO_Port GPIOB
#define TILT_SEL0_Pin GPIO_PIN_6
#define TILT_SEL0_GPIO_Port GPIOB

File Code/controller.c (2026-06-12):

/**
 * @file controller.h
 * @brief High-level target tracking controller interface.
 *
 * This module coordinates the Pixy2 camera, TF-Luna LiDAR,
 * pan/tilt motor drivers, and laser module to implement
 * closed-loop target tracking.
 *
 * @authors Tyler Lum, Colby Cordoba, Sam Nunes
 * @date June 2026
 */

#ifndef CONTROLLER_H
#define CONTROLLER_H

// prototypes here

#endif
#include "controller.h"
#include "motor_driver.h"
#include "Laser.h"

/* PID gains:
 * Kp: raise until it tracks without lagging, lower if it oscillates
 * Ki: small value to remove steady state error, keep near 0 to start
 * Kd: raise until it stops overshooting targets
 */

#define PAN_KP  20.0f
#define PAN_KI  0.0f
#define PAN_KD  5.0f

#define TILT_KP 20.0f
#define TILT_KI 0.0f
#define TILT_KD 5.0f

#define PID_INTEGRAL_MAX  500.0f
#define PID_OUTPUT_MAX    4999.0f


#define LASER_MAX_RANGE_CM 300u

typedef struct{
	float kp;
	float ki;
	float kd;
	float integral;
	float prev_error;
	float integral_max;
	float output_max;
} PID_t;

static PID_t pan_pid;
static PID_t tilt_pid;
extern ADC_HandleTypeDef hadc1;

static int16_t pan_search_direction = 1;

static void PID_Init(PID_t *pid, float kp, float ki, float kd,
                     float integral_max, float output_max);

static float PID_Update(PID_t *pid, float error);

static void PID_Reset(PID_t *pid);

static uint16_t Controller_ReadADC(uint32_t channel);

// INIT / RESET

void Controller_Init(void)
{
    PID_Init(&pan_pid, PAN_KP, PAN_KI, PAN_KD,
             PID_INTEGRAL_MAX, PID_OUTPUT_MAX);

    PID_Init(&tilt_pid, TILT_KP, TILT_KI, TILT_KD,
             PID_INTEGRAL_MAX, PID_OUTPUT_MAX);
}

void Controller_Reset(void)
{
    PID_Reset(&pan_pid);
    PID_Reset(&tilt_pid);
}

// ADC FEEDBACK

static uint16_t Controller_ReadADC(uint32_t channel)
{
    ADC_ChannelConfTypeDef sConfig = {0};
    uint16_t adc_value = 0;

    sConfig.Channel = channel;
    sConfig.Rank = 1;
    sConfig.SamplingTime = ADC_SAMPLETIME_84CYCLES;

    if (HAL_ADC_ConfigChannel(&hadc1, &sConfig) != HAL_OK)
    {
        return 0;
    }

    HAL_ADC_Start(&hadc1);

    if (HAL_ADC_PollForConversion(&hadc1, 10) == HAL_OK)
    {
        adc_value = (uint16_t)HAL_ADC_GetValue(&hadc1);
    }

    HAL_ADC_Stop(&hadc1);

    return adc_value;
}

uint16_t Controller_ReadPanADC(void)
{
    return Controller_ReadADC(ADC_CHANNEL_0);   // PA0 = PAN_FB
}

uint16_t Controller_ReadTiltADC(void)
{
    return Controller_ReadADC(ADC_CHANNEL_1);   // PA1 = TILT_FB
}

// TILT HOMING

uint8_t Controller_TiltIsHome(void)
{
    uint16_t tilt_adc = Controller_ReadTiltADC();

    // Your measured vertical center was about 3856.
    // This accepts 3820 to 3890 as close enough to vertical.
    if (tilt_adc >= 3820 && tilt_adc <= 3890)
    {
        return 1u;
    }

    return 0u;
}

void Controller_HomeTiltStep(void)
{
    uint16_t tilt_adc = Controller_ReadTiltADC();

    // If tilt ADC is above vertical center, move back toward center.
    if (tilt_adc > 3890)
    {
        TiltMotor_Set(600);
    }

    // If tilt ADC is below vertical center, move the opposite direction.
    else if (tilt_adc < 3820)
    {
        TiltMotor_Set(-600);
    }

    // If close to vertical, stop.
    else
    {
        TiltMotor_Set(0);
    }
}

void Controller_HomeTiltBlocking(uint32_t timeout_ms)
{
    uint32_t start_time = HAL_GetTick();

    while (Controller_TiltIsHome() == 0u)
    {
        Controller_HomeTiltStep();

        // Important: pan should NOT move while tilt is homing.
        PanMotor_Set(0);
        Laser_Off();

        if ((HAL_GetTick() - start_time) > timeout_ms)
        {
            break;
        }

        HAL_Delay(20);
    }

    Motors_Stop();
}

// ADC LIMIT PROTECTION

int16_t Controller_ApplyTiltLimits(int16_t tilt_cmd)
{
    uint16_t tilt_adc = Controller_ReadTiltADC();

    if (tilt_adc >= 4090 && tilt_cmd < 0)
    {
        tilt_cmd = 0;
    }

    if (tilt_adc <= 1600 && tilt_cmd > 0)
    {
        tilt_cmd = 0;
    }

    return tilt_cmd;
}

int16_t Controller_ApplyPanLimits(int16_t pan_cmd)
{
    uint16_t pan_adc = Controller_ReadPanADC();

    // Left-side limit
    if (pan_adc >= 2550 && pan_adc <= 2750 && pan_cmd < 0)
    {
        pan_cmd = 0;
    }

    // Right-side limit
    if (pan_adc >= 3150 && pan_adc <= 3220 && pan_cmd > 0)
    {
        pan_cmd = 0;
    }

    return pan_cmd;
}
// SEARCH MODE

void Controller_SearchMode(void)
{
    uint16_t pan_adc = Controller_ReadPanADC();

    Laser_Off();

    // Do NOT pan until tilt is back at vertical home.
    if (Controller_TiltIsHome() == 0u)
    {
        PanMotor_Set(0);
        Controller_HomeTiltStep();
        return;
    }

    // Once tilt is vertical, then pan can search.
    if (pan_adc >= 3150 && pan_adc <= 3220)
    {
        pan_search_direction = -1;
    }
    else if (pan_adc >= 2550 && pan_adc <= 2750)
    {
        pan_search_direction = 1;
    }

    PanMotor_Set(pan_search_direction * 700);
}

// OPTIONAL FULL CONTROLLER UPDATE
void Controller_Update(PixyTarget_t *camera_target, Lidar_t *lidar)
{
    bool target_found = Camera_FindTarget(camera_target);

    if (!target_found)
    {
        PanMotor_Set(0);
        Laser_Off();
        Controller_SearchMode();
        Controller_Reset();
        return;
    }

    float pan_speed = PID_Update(&pan_pid, (float)camera_target->x_error);
    float tilt_speed = PID_Update(&tilt_pid, (float)camera_target->y_error);

    int16_t pan_cmd = Controller_ApplyPanLimits((int16_t)pan_speed);
    int16_t tilt_cmd = Controller_ApplyTiltLimits((int16_t)tilt_speed);

    PanMotor_Set(pan_cmd);
    TiltMotor_Set(tilt_cmd);

    LidarStatus_t lidar_status = Lidar_ReadFrame(lidar, 10u);

    bool centered = Camera_TargetCentered(camera_target);
    bool in_range = (lidar_status == LIDAR_OK) &&
                    Lidar_ObjectDetected(lidar, LASER_MAX_RANGE_CM);

    if (centered && in_range)
    {
        Laser_On();
    }
    else
    {
        Laser_Off();
    }
}

// PID FUNCTIONS

static void PID_Init(PID_t *pid, float kp, float ki, float kd,
                     float integral_max, float output_max)
{
    pid->kp = kp;
    pid->ki = ki;
    pid->kd = kd;
    pid->integral = 0.0f;
    pid->prev_error = 0.0f;
    pid->integral_max = integral_max;
    pid->output_max = output_max;
}

static float PID_Update(PID_t *pid, float error)
{
    pid->integral += error;

    if (pid->integral > pid->integral_max)
    {
        pid->integral = pid->integral_max;
    }
    else if (pid->integral < -pid->integral_max)
    {
        pid->integral = -pid->integral_max;
    }

    float derivative = error - pid->prev_error;
    pid->prev_error = error;

    float output = (pid->kp * error) +
                   (pid->ki * pid->integral) +
                   (pid->kd * derivative);

    if (output > pid->output_max)
    {
        output = pid->output_max;
    }
    else if (output < -pid->output_max)
    {
        output = -pid->output_max;
    }

    return output;
}
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

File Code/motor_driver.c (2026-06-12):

/**
 * @file motor_driver.c
 * @brief Implementation of the pan and tilt motor driver.
 *
 * The driver converts signed speed commands into motor direction GPIO states and
 * PWM duty-cycle values. The pan axis uses TIM4 channel 3 and the tilt axis uses
 * TIM4 channel 4. Keeping this code in a driver prevents the main control loop
 * from directly manipulating PWM registers and GPIO pins.
 */

#include "motor_driver.h"

extern TIM_HandleTypeDef htim4;

/**
 * @brief Starts PWM generation and places both motors in a stopped state.
 *
 * The SEL0 pins are asserted to configure or enable the motor-driver channels.
 * Both PWM outputs are started before Motors_Stop() clears the duty cycles and
 * direction pins.
 */
void MotorDriver_Init(void)
{
    HAL_TIM_PWM_Start(&htim4, TIM_CHANNEL_3);
    HAL_TIM_PWM_Start(&htim4, TIM_CHANNEL_4);

    HAL_GPIO_WritePin(GPIOB, PAN_SEL0_Pin, GPIO_PIN_SET);
    HAL_GPIO_WritePin(GPIOB, TILT_SEL0_Pin, GPIO_PIN_SET);

    Motors_Stop();
}

/**
 * @brief Sets the pan motor speed and direction.
 *
 * Positive values select one direction, negative values select the opposite
 * direction, and the magnitude becomes the PWM compare value. The command is
 * clamped to the timer range of +/-4999.
 *
 * @param speed Signed pan command from -4999 to +4999.
 */
void PanMotor_Set(int16_t speed)
{
    if(speed > 4999) speed = 4999;
    if(speed < -4999) speed = -4999;

    if(speed >= 0)
    {
        HAL_GPIO_WritePin(GPIOB, PAN_INA_Pin, GPIO_PIN_SET);
        HAL_GPIO_WritePin(GPIOB, PAN_INB_Pin, GPIO_PIN_RESET);
    }
    else
    {
        HAL_GPIO_WritePin(GPIOB, PAN_INA_Pin, GPIO_PIN_RESET);
        HAL_GPIO_WritePin(GPIOB, PAN_INB_Pin, GPIO_PIN_SET);
        speed = -speed;
    }

    __HAL_TIM_SET_COMPARE(&htim4, TIM_CHANNEL_3, speed);
}

/**
 * @brief Sets the tilt motor speed and direction.
 *
 * Positive values select one direction, negative values select the opposite
 * direction, and the magnitude becomes the PWM compare value. The command is
 * clamped to the timer range of +/-4999.
 *
 * @param speed Signed tilt command from -4999 to +4999.
 */
void TiltMotor_Set(int16_t speed)
{
    if(speed > 4999) speed = 4999;
    if(speed < -4999) speed = -4999;

    if(speed >= 0)
    {
        HAL_GPIO_WritePin(GPIOB, TILT_INA_Pin, GPIO_PIN_SET);
        HAL_GPIO_WritePin(GPIOB, TILT_INB_Pin, GPIO_PIN_RESET);
    }
    else
    {
        HAL_GPIO_WritePin(GPIOB, TILT_INA_Pin, GPIO_PIN_RESET);
        HAL_GPIO_WritePin(GPIOB, TILT_INB_Pin, GPIO_PIN_SET);
        speed = -speed;
    }

    __HAL_TIM_SET_COMPARE(&htim4, TIM_CHANNEL_4, speed);
}

/**
 * @brief Stops both motor channels and clears all direction pins.
 *
 * This function is used during initialization, when the camera target is lost,
 * and whenever the mechanism needs to be placed into a safe non-moving state.
 */
void Motors_Stop(void)
{
    __HAL_TIM_SET_COMPARE(&htim4, TIM_CHANNEL_3, 0);
    __HAL_TIM_SET_COMPARE(&htim4, TIM_CHANNEL_4, 0);

    HAL_GPIO_WritePin(GPIOB, PAN_INA_Pin|PAN_INB_Pin|TILT_INA_Pin|TILT_INB_Pin, GPIO_PIN_RESET);
}

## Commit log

2026-06-11 Update motor type from DC motors to servo motors
2026-06-16 Update fmt.Println message from 'Hello' to 'Goodbye'
2026-06-16 Create CAD
2026-06-16 Rename HW 3.f3z to Final PCB Design.f3z
    [Final PCB Design.f3z, HW 3.f3z]

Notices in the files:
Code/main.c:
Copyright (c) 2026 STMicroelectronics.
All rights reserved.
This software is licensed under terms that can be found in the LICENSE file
